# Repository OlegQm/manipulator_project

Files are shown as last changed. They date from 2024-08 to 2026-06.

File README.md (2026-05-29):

# Autonomous Object Recognition Manipulator

This is a solo project by **Oleh Savchenko** focused on building a self-made autonomous manipulator that can detect objects and react to user commands from a mobile app. The repository now combines hardware control, on-device vision, mobile UX, and a separate multimodal chatbot service for image Q&A.

---

## 📷 Photos

bird_photo_for_readme_1
bird_photo_for_readme_2

---

## Project Structure

```
├── 3D_models
│   └── [3D models for printing device components]
├── programs
│   ├── arduino
│   │   ├── servos_and_led             # Servo + LED control sketch
│   │   └── old/esp32                  # Legacy ESP32 camera code
│   ├── mobile
│   │   └── manipulatorMobileApp       # Mobile app source code
│   ├── multimodal_chatbot             # FastAPI + LangGraph image Q&A service
│   └── objects_detection
│       ├── pt_to_hef_converter        # Convert trained models to HEF format
│       ├── robotic_arm_scripts        # Raspberry Pi + Hailo runtime scripts
│       └── custom_model               # Custom YOLO model configs and training assets
└── README.md
```

### 3D\_models

Contains all 3D-printable models for assembling the manipulator device.

### programs

* **arduino**: Arduino sketches for low-level manipulator control (servos/LED) and archived ESP32 experiments.
* **mobile/manipulatorMobileApp**: Xamarin.Forms mobile client (Android/iOS) used to configure bot access, send commands, and work with detected object lists.
* **objects\_detection**: Raspberry Pi object detection stack, custom model assets, and scripts for manipulator interaction.
* **multimodal\_chatbot**: Dockerized FastAPI service (LangGraph-based) that accepts text + image and returns responses, with Redis sessions and Nginx basic auth.

---

## 🌐 System Workflow

1. **User Request**: The user sends a command from the mobile app (for example, request screenshot / object list / selection).
2. **Bot Transport Layer**: Communication is currently handled through Telegram bot endpoints to keep infrastructure simple and low-cost.
3. **Detection Runtime**: The Raspberry Pi module in `programs/objects_detection/robotic_arm_scripts` runs inference (with Hailo acceleration when enabled).
4. **Result Delivery**: The app receives an image and/or recognized object names and renders them for user interaction.
5. **Selection Command**: The user chooses an object or action, and the command is sent back through the same channel.
6. **Actuation**: The detection/control side sends control signals to Arduino logic that drives the manipulator servos.

In parallel, the repository also includes `programs/multimodal_chatbot`, a standalone API flow for image + text question answering.



---

## 🍓 Raspberry Pi

The Raspberry Pi is the main compute node for on-device vision and control scripts. In the current setup, it works as the bridge between camera inference and actuator logic, and interfaces with:

* **Battery pack**
* **Arduino**
* **Display**
* **Power button**

raspberry_pi_newest_device

---

## 🤖 Hailo AI Kit

The project uses the Hailo AI Kit as a hardware accelerator for real-time detection. The measured project-level comparison remains:

* **Raspberry Pi CPU**: YOLOv8n at 256×256 resolution → \~9 FPS
* **Hailo AI Kit**: YOLOv8m at 640×640 resolution → >100 FPS

ai_kit_newest_device

---

## 🖨️ 3D Models

The mechanical design combines EEZYbotARM-based parts (purple) with custom printed components (black) adapted for this build.



---

## 📱 Mobile Application

The mobile client is implemented with Xamarin.Forms and currently communicates with the device via Telegram bots. Typical setup:

1. Create two bots in a single chat:

   * **Manipulator bot** (device-side command receiver)
   * **User bot** (app-side interaction bot)
2. In the app, provide bot token and chat ID in the server settings screen.
3. Choose one of two operation modes:

   * **Objects List**: Manage/filter object names and send direct selection commands.
   * **Possible Objects**: Request fresh screenshot + caption from the device and pick from currently detected items.
4. Send a request, review response, and dispatch selection/search commands.

The app also supports object filtering by text prompt and by photo, which helps when the exact object name is unknown.




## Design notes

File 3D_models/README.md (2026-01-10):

# 3D Parts for the Device

- 1x - print once
- 2x - print twice
- 3x - print three times
- 4x - print four times

The `1x` folder also contains an `old` folder that stores the 3D models needed for earlier versions of the robotic arm.

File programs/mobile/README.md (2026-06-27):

# manipulatorMobileApp

`manipulatorMobileApp` is a Xamarin.Forms mobile application used to control the
robotic arm prototype, request camera screenshots through Telegram, select tracked
objects, and optionally discuss the latest image with a multimodal chatbot backend.

---

## Features

- Stores Telegram server/bot settings locally with SQLite.
- Sends control commands to the robotic arm through Telegram Bot API.
- Requests the current camera image and displays the returned object list.
- Sends `/selection`, `/searching`, and `/flashlight` commands.
- Maintains a local object database and supports manual, text-prompt, and photo-based filtering.
- Opens a chat page that sends the displayed image to the chatbot backend and keeps a server-side session for follow-up questions.

---

## Prerequisites

- **Visual Studio Community 2022**
  - Ensure you have the **Xamarin.Forms** workload installed
- **Android SDK** (installed via Visual Studio installer)
- **Xcode** (for iOS builds on macOS)
- .NET tooling that ships with Visual Studio for Xamarin development
- Telegram bot token and chat/channel ID for communication with the robotic arm
- Optional chatbot server URL and Basic Auth credentials
- `api_key.txt` in the application data path when OpenAI-based object-list filtering is used

---

## Solution structure

`manipulatorMobileApp.sln`

- `manipulatorMobileApp/` — shared Xamarin.Forms project
  - `App.xaml`, `App.xaml.cs` — app bootstrap and navigation root
  - `MainPage.xaml(.cs)` — entry page
  - `Views/`
    - `ModeSelectionPage` — chooses operating mode
    - `NotesPage`, `NoteAddingPage` — notes list and creation flow
    - `ScreenshotPage` — camera screenshot, available objects, and chatbot entry
    - `ChatPage` — image-based chatbot conversation
  - `Services/`
    - `TelegramService.cs` — Telegram Bot API communication
    - `ChatbotService.cs` — REST client for the multimodal chatbot backend
  - `Helpers/`
    - `SearchingToggleHelper.cs`, `FlashlightToggleHelper.cs` — shared Telegram command toggles
    - `SafeAreaHelper.cs` — platform-safe layout helper
  - `Controls/`
    - `ChatInputEditor.cs` — custom chat input editor
  - `Data/`
    - `RecordsDB.cs` — SQLite helper for `Record` entities
    - `ServersDB.cs` — SQLite helper for `Server` entities
  - `Models/`
    - `Record.cs`, `Server.cs`, `ChatMessage.cs` — model definitions
  - `IToast.cs`, `IFileHelper.cs` — dependency-service contracts implemented per platform
- `manipulatorMobileApp.Android/`
  - `MainActivity.cs` — Android entry point
  - `FileHelperDroid.cs`, `ToastDroid.cs` — Android-specific DI implementations
  - `Renderers/ChatInputEditorRenderer.cs` — Android renderer for the chat input
  - `Resources/` — icons, styles, manifests, assets
- `manipulatorMobileApp.iOS/`
  - `AppDelegate.cs`, `Main.cs` — iOS entry points
  - `FileHelperiOS.cs`, `ToastIOS.cs` — iOS-specific DI implementations
  - `Assets.xcassets/`, `Resources/`, `Info.plist`, entitlements

---

## App flow and logic

- **Startup** (`App.xaml.cs`)
  - Initializes dark theme and navigation root (`NavigationPage -> MainPage`).
  - Lazy-creates SQLite databases for notes (`RecordsDB`) and servers (`ServersDB`) in `LocalApplicationData`.
  - Loads a list of standard object names from `names.names` via `IFileHelper`; exposes it as `GlobalWordsArray`.
  - On failure to load words, shows a toast via platform `IToast`.

- **Main screen (servers)** (`MainPage`)
  - Editors for server name, bot token, chat ID, optional chatbot URL, and optional Basic Auth credentials; saves to `ServersDB`.
  - Lists saved servers with swipe-to-delete and “Delete All”.
  - On selection, populates editors from the chosen server.
  - “Start”/toolbar “Start” opens **ModeSelectionPage** with the current Telegram settings and optional chatbot settings. Server name, bot token, and chat ID are required.

- **Mode selection** (`ModeSelectionPage`)
  - Two branches: **NotesPage** (“OBJECTS LIST”) and **ScreenshotPage** (“POSSIBLE OBJECTS”).
  - `NotesPage` receives the Telegram token/chat ID.
  - `ScreenshotPage` also receives the chatbot URL and authentication values.

- **Notes list & actions** (`NotesPage`)
  - Loads/saves `Record` entries from `RecordsDB`; search bar filters locally by title.
  - “Add” opens `NoteAddingPage` for create/edit; swipe-to-delete removes a record; “Delete All” drops and recreates the table.
  - **Edit mode** toggle: tap navigates to `NoteAddingPage` for the selected record; otherwise tap sends `/selection <Title>` to the Telegram bot (HTTP POST).
  - **Default Buttons**: reloads `GlobalWordsArray` into the DB after confirmation, replacing existing entries.
  - **Filter by prompt**: sends a text prompt with the known object list to OpenAI (`gpt-4o-mini`), splits the response into keywords, filters records by those keywords.
  - **Filter by photo**: captures a photo (permissions via `Xamarin.Essentials`), resizes with SkiaSharp, calls OpenAI vision (`gpt-4o-mini`) with the image and known object list, then filters records by returned keywords.
  - **OFF/ON searching**: toggles `/searching 0/1` via Telegram; **Turn on/off flashlight** sends `/flashlight ON/OFF`.

- **Add/Edit note** (`NoteAddingPage`)
  - Binds a `Record`; loads by ID when navigated from edit mode.
  - Saves or updates on “Save”; deletes on “Delete”; auto-updates DB on text/title change to keep timestamps in sync.
  - Toolbar utilities: clear text, replace double spaces, scroll to top/bottom, change text/background colors.
  - Auto-generates a title from the first 45 chars of the description if the title is empty.

- **Screenshot & available objects** (`ScreenshotPage`)
  - Initially displays a built-in placeholder image and enables the Chat toolbar item, so the chatbot can be tested even before a real screenshot is received.
  - “SCREENSHOT” sends `/get_image` to the Telegram bot, then polls `getUpdates` to fetch the latest photo and caption; displays the image and splits the caption into available object items.
  - Selecting an item sends `/selection <word>` to the bot.
  - Toolbar toggles send `/searching 0/1` and `/flashlight ON/OFF`.
  - The Chat toolbar item opens `ChatPage` with the currently displayed image. If no Telegram screenshot has been fetched yet, the placeholder image is used.

- **Chatbot conversation** (`ChatPage`)
  - Creates a server-side chatbot session with `POST /api/v1/sessions` when the page opens.
  - Sends the currently displayed image as Base64 only with the first chat message.
  - Sends later messages as text-only; the backend keeps the image in the same session and can reuse it for follow-up questions.
  - Deletes the session with `DELETE /api/v1/sessions/{session_id}` when the chat page disappears. Errors during deletion are intentionally ignored because server cleanup also handles expired sessions.

---

## Data and services

- **SQLite**: `RecordsDB` and `ServersDB` wrap SQLiteAsyncConnection; create tables on first use; provide CRUD plus helpers (last server, filter records by keywords, drop/reset).
  `Server` records also store optional chatbot URL, username, and password.
- **DependencyService contracts**:
  - `IFileHelper` — resolve platform file paths (used to load `names.names`, `api_key.txt`).
  - `IToast` — platform toast notifications.
- **External APIs**:
  - Telegram Bot API (`sendMessage`, `getUpdates`, `getFile`) for bot control, screenshot retrieval, and selection commands.
  - OpenAI Chat/Vision (`gpt-4o-mini`) for object-list filtering in `NotesPage`.
  - Multimodal chatbot REST API (`/api/v1/sessions`, `/api/v1/chat`, `/api/v1/sessions/{id}`) for image-based conversation in `ChatPage`.
  - Network access checked via `Xamarin.Essentials.Connectivity`; camera via `MediaPicker` with runtime permissions.

---

## Build and run

1. **Open in Visual Studio 2022**
   - Launch Visual Studio Community 2022
   - Select **File → Open → Project/Solution**
   - Navigate to `manipulatorMobileApp/manipulatorMobileApp.sln` and open it

2. **Restore NuGet packages**
   - In **Solution Explorer**, right-click the solution and choose **Restore NuGet Packages**

3. **Configure runtime values**
   - Add a Telegram bot token and chat ID on the main screen.
   - Add chatbot URL and Basic Auth values only if `ChatPage` should call the multimodal chatbot backend.
   - Add `api_key.txt` only if prompt/photo filtering in `NotesPage` should use OpenAI.

4. **Deploy to device or emulator**
   - Set the **Startup Project** to your desired platform (Android or iOS)
   - Choose an emulator or connected device
   - Press **F5** to build and run

---

## Usage notes

- Use **OBJECTS LIST** when selecting from the local object database.
- Use **POSSIBLE OBJECTS** when requesting a live camera screenshot and selecting one of the detected objects.
- Open **Chat** from the screenshot screen to ask questions about the currently displayed image.
- The first chatbot message includes the image; follow-up messages rely on the same server-side session.

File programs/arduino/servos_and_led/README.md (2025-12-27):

# Background

The device is controlled by three servos via Arduino:
The left and right servos are used to adjust the camera height.
The bottom servo (in the base) rotates the device.

I could have done without Arduino, but I added it as an extra layer against high-voltage events and incorrect wiring.

# Arduino Servo Controller

This sketch reads rotation angles and drives three servo motors on an Arduino Uno.

## Wiring

- **Flashlight** → Data Pin 5
- **Base servo** → Data Pin 4
- **Left servo** (camera facing you) → Data Pin 3
- **Right servo** → Data Pin 2 
- **All servos and flashlight** → +5 V (use common ground with Arduino)

## Installation

1. Open the `.ino` file in the Arduino IDE. 
2. Select **Arduino Uno** as the board. 
3. Upload at 115200 bps.

## Usage

1. Send angle data over Serial (e.g. `$090090060` (`$090` - 90 deg, `$090` - 90 deg, `$060` - 60 deg)).
2. The sketch parses each value and moves the corresponding servo.
3. Send `@ON` to turn the flashlight on and `@OFF` to turn it off.

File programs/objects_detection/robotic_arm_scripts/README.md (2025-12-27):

# Robotic arm with objects following system

This folder contains the detection module that runs on a Raspberry Pi with a Hailo accelerator. It uses a custom model, based on YOLOv8m model to detect objects for the manipulator project.

## Setup

Run the installation script to create the virtual environment and download necessary resources:

```bash
cd hailo_scripts
./install.sh
cd ..
```

## Running

Start the detection pipeline with the provided model:

```bash
python3 hailo_remote_detection.py -i rpi -u \
    --hef models/dataset_v5_models/hailo_models/own_yolov8m_lca_light_v2_quantized_model.hef \
    --labels-json hailo_scripts/labels.json
```

Adjust the model or labels if you use your own dataset.

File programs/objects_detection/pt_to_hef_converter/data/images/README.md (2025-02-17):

Images from your dataset (in my case 3664 validation images)

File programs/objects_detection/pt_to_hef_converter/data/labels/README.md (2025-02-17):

Labels from your dataset (in my case 3664 validation labels), corresponding to images

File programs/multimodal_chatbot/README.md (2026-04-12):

# Multimodal Chatbot

A multimodal chatbot REST API that accepts images and text to answer questions. Built with **FastAPI**, **LangGraph**, and **OpenAI GPT-5-mini**.

## Features

- **Multimodal**: Send images (base64) + text questions, get intelligent answers
- **Session-based**: Per-session chat history stored in Redis
- **Token management**: Tracks token usage with tiktoken, enforces context window limits
- **Auto-cleanup**: Expired sessions (>1h inactivity) automatically purged every 10 minutes
- **Dockerized**: Single `docker compose up` starts all services
- **Secured**: Nginx reverse proxy with HTTP Basic Authentication
- **CI/CD**: GitHub Actions pipeline with automated tests and SSH deployment

## Quick Start

### Prerequisites

- Docker and Docker Compose
- OpenAI API key

### 1. Configure environment

```bash
cd programs/multimodal_chatbot
cp .env.example .env
# Edit .env with your actual values (API key, auth credentials)
```

### 2. Start the application

```bash
docker compose up -d --build
```

This starts 3 services:
- **app** — FastAPI application on internal port 8000
- **redis** — Redis 7 for session storage
- **nginx** — Reverse proxy on port 80 with basic auth

### 3. Verify

```bash
curl http://localhost/health
# {"status": "ok", "redis": "connected"}
```

## API Usage

All endpoints (except `/health`) require HTTP Basic Auth.

### Create a session

```bash
curl -u admin:password -X POST http://localhost/api/v1/sessions
# {"session_id": "abc-123...", "created_at": "..."}
```

### Send a text message

The client sends only the current message. The service loads the existing
conversation history from Redis by `session_id`.

```bash
curl -u admin:password -X POST http://localhost/api/v1/chat \
  -H "Content-Type: application/json" \
  -d '{"session_id": "abc-123...", "message": "Hello!"}'
```

### Send an image + question

```bash
IMAGE_B64=$(base64 -w0 photo.jpg)
curl -u admin:password -X POST http://localhost/api/v1/chat \
  -H "Content-Type: application/json" \
  -d "{\"session_id\": \"abc-123...\", \"message\": \"What is this?\", \"image\": \"$IMAGE_B64\"}"
```

### Get chat history

This endpoint is optional for clients that need to display or debug the stored
conversation. It is not required when sending messages to `/api/v1/chat`.

```bash
curl -u admin:password http://localhost/api/v1/sessions/abc-123.../history
```

### Delete a session

```bash
curl -u admin:password -X DELETE http://localhost/api/v1/sessions/abc-123...
```

## Environment Variables

| Variable | Default | Description |
|---|---|---|
| `OPENAI_API_KEY` | — | **Required.** OpenAI API key |
| `OPENAI_MODEL` | `gpt-4o-mini` | OpenAI model name |
| `REDIS_URL` | `redis://redis:6379/0` | Redis connection string |
| `SESSION_TTL_SECONDS` | `3600` | Session inactivity timeout (seconds) |
| `CLEANUP_INTERVAL_SECONDS` | `600` | Cleanup job interval (seconds) |
| `MAX_CONTEXT_TOKENS` | `100000` | Max tokens per session |
| `BASIC_AUTH_USER` | `admin` | Nginx basic auth username |
| `BASIC_AUTH_PASSWORD` | `changeme` | Nginx basic auth password |
| `LOG_LEVEL` | `INFO` | Python logging level |

## Project Structure

```
programs/multimodal_chatbot/
├── docker-compose.yaml       # Docker services definition
├── pytest.ini                # pytest configuration
├── .env / .env.example       # Environment configuration
├── app/
│   ├── Dockerfile            # App container image
│   ├── requirements.txt      # Runtime Python dependencies
│   ├── main.py               # FastAPI entry point
│   ├── config.py             # Pydantic BaseSettings
│   ├── models/               # Request/response schemas
│   ├── routers/              # API endpoints
│   ├── services/             # Business logic (agent, sessions, cleanup)
│   └── tools/                # LangGraph tools
├── nginx/                    # Nginx config + Dockerfile
├── tests/                    # pytest test suite
│   ├── Dockerfile            # Test runner container image
│   └── requirements.txt      # Test dependencies (references app/requirements.txt)
└── agent-instructions/       # Documentation
```

## Testing

Tests run inside a dedicated Docker container via the `test` profile:

```bash
# Run all tests in Docker (recommended)
cd programs/multimodal_chatbot
docker compose --profile test run --rm tests
```

Each container has its own `requirements.txt`:
- `app/requirements.txt` — runtime dependencies
- `tests/requirements.txt` — test dependencies (references app deps via `-r`)

## Deployment

Push to `main` branch triggers automatic deployment via GitHub Actions:
1. Tests run in CI
2. On success, code is synced to EC2 via SSH
3. Docker Compose rebuilds and restarts services

See [agent-instructions/deployment/server-setup.md](agent-instructions/deployment/server-setup.md) for manual setup.

## Documentation

- [Implementation Plan](agent-instructions/PLAN.md)
- [Architecture Overview](agent-instructions/architecture/overview.md)
- [API Reference](agent-instructions/api/endpoints.md)
- [Deployment Guide](agent-instructions/deployment/server-setup.md)

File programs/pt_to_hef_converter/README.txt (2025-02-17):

1) Create environment (YOLO) with Python 3.8.20 (`venv_yolov8` in my case):

After that activate environment:
`source venv_yolov8/bin/activate`

Then donload the 3.27.0 Hailo dataflow compiler (https://hailo.ai/?dl_dev=1&file=8791984ee2b2999850f5a55fbdb8c46f)
from https://hailo.ai/developer-zone/software-downloads/. You may need to register here.
Copy the downloaded file to the same directory as `hailo_model_zoo-2.11.0-py3-none-any.whl`.

And install modules:
`pip install -r yolo_env_requirements.txt`

Then copy your .pt model in `/pt_to_hef_converter`,
for instance `yolov8m_model_v15_640.pt` (my case), and execute in terminal:
`yolo export model=./yolov8m_model_v15_640.pt imgsz=640 format=onnx opset=11`

2) Create environment (HAILO) with Python 3.8.20 (`venv_hailo` in my case):

After that activate environment:
`source venv_hailo/bin/activate`

And install modules:
`pip install -r hailo_env_requirements.txt`

Then enter your model name instead of `yolov8m_model_v15_640`, `yolov8m_model_v15_640.onnx`
and `yolov8m_model_v15_640.har` in `steps/parse.py`. `yolov8m_640_v15` is the folder where the
`yolov8m_model_v15_640.onnx` and `yolov8m_model_v15_640.har` will be saved:

`onnx_model_name = 'yolov8m_model_v15_640'`
`onnx_path = 'yolov8m_640_v15/yolov8m_model_v15_640.onnx'`
`har_path = 'yolov8m_640_v15/yolov8m_model_v15_640.har'`

Then move to https://netron.app/ (or any other model) and visualize your `.onnx` (in the future instructions I will refer
to yolov8m_640_v15/yolov8m_model_v15_640.onnx` visualization, that's my case):
On the image you will find the last `Concat` layer, which includes the 3 arrows (`/model.22/Concat_3` on
`yolov8m_model_v15_640.onnx` visualization).

Then go up the leftmost branch of this word all the way to `Reshape'. After that you will see 2 `Conv` layers.
Click on the left one (`/model.22/cv2.0/cv2.0.2/Conv` in my case) and copy its name (`name`),
do the same with the second one (`/model.22/cv3.0/cv3.0.2/Conv` in my case)
and copy its name right after the first one.
Do the same with the rest of the layers, saving all the names one after the other. I have such a list:
`[
        '/model.22/cv2.0/cv2.0.2/Conv',
        '/model.22/cv3.0/cv3.0.2/Conv',
        '/model.22/cv2.1/cv2.1.2/Conv',
        '/model.22/cv3.1/cv3.1.2/Conv',
        '/model.22/cv2.2/cv2.2.2/Conv',
        '/model.22/cv3.2/cv3.2.2/Conv'
]`
After that, copy this list instead of mine into `steps/parse.py`.

Then go to the terminal and execute:
`python3.8 steps/parse.py`

3) Add images to `data/images` following the instructions in `data/images/README.txt`, and add captions to `data/labels`.
Also add the images to `calibration_set` as instructed in `calibration_set/README.txt`.
Then open `steps/optimize.py` and in `MODEL_NAME`, copy the same name that was in the `steps/parse.py` file in `har_path`.
Now enter the number of classes from the dataset in `NUM_CLASSES` and enter the image size in the `.pt` model to `IMG_SIZE`.

Then visualise the `.har` model using the `hailo visualizer yolov8m_640_v15/yolov8m_model_v15_640.har`
command (`yolov8m_640_v15/yolov8l_model_v16_640.svg` in my case).

Now find all 6 output layers: `output_layer1`, `output_layer2`,..., `output_layer6` and look at the `conv` layers in front of each of them.
In my case (`yolov8l_model_v16_640.svg`) these are layers `conv57`, `conv58`, `conv70`, `conv71`, `conv82` and `conv83`, keep these names.
After that copy the file `config/postprocess_config/yolov8m_nms_config.json` to yourself and replace my names with your own,
you can also rename the file as desired. Also specify the path to this file in `alls`:

alls = '''
quantisation_param([conv58, conv71, conv83], force_range_out=[0.0, 1.0])
normalisation1 = normalization([0.0, 0.0, 0.0, 0.0], [255.0, 255.0, 255.0])
nms_postprocess("config/postprocess_config/yolov8m_nms_config.json" meta_arch=yolov8, engine=cpu)
'''
Also in `alls` replace the names `[conv58, conv71, conv83]` with the names of the `conv` layers before `output_layer2`,
`output_layer4` and `output_layer6`.

Then go to the terminal and execute:
`python3.8 steps/optimize.py`

4) Go to `steps/compile.py`. Replace `model_name` with your model name. Then go to the terminal and execute:
`python3.8 steps/compile.py`

After this command you will get your `.hef` file, the command may take a long time.

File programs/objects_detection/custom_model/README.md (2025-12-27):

Custom Ultralytics YOLO Extensions
==================================

This repository packages a customized [Ultralytics 8.3.160](https://community.ultralytics.com/t/new-release-ultralytics-v8-3-160/1185) build with additional layers for better small-object detection. The key addition is Local Context Attention (LCA), wired into Ultralytics' registry so it can be used directly in model YAMLs. A reference model (`own_yolov8m_lca_light_v2.yaml`) shows how to integrate the new blocks.

Contents
--------
- `ultralytics_custom/`: editable Ultralytics package with custom modules registered.
- `ultralytics_custom/ultralytics/nn/modules/custom_modules.py`: LCA, ConvLCA, and a Hailo-friendly Detect head.
- `own_yolov8m_lca_light_v2.yaml`: example YOLOv8 model using the custom layers.
- `trainer.py`: training entrypoint with default hyperparameters and resume/debug switches.
- `setup_yolo_env.sh`: helper to provision a Python 3.12 venv, install GPU drivers, and install the editable package.

Requirements
------------
- Python 3.12 (script installs `python3.12` and `python3.12-venv` on Ubuntu).
- NVIDIA driver/toolkit for GPU training (script installs driver 535).
- Access to the dataset repo `https://github.com/OlegQm/manipulator_project_datasets` (clone happens in the setup script).

Quickstart (scripted)
---------------------
1. Set the path to this project in `setup_yolo_env.sh`:
   - Edit `PATH_TO_CUSTOM_YOLO_MODEL_TRAINER` to the parent directory that contains `ultralytics_custom`.
2. Run the setup:
   ```bash
   bash setup_yolo_env.sh
   ```
   The script will clone the dataset repo (if accessible), fetch a sample image, create the `yolo_trainer` venv, and install the package in editable mode.

Manual Installation
-------------------
```bash
cd ultralytics_custom
python3.12 -m venv ../yolo_trainer
source ../yolo_trainer/bin/activate
pip install --upgrade pip
pip install -e .
```
If you need the demo image, download it to `ultralytics_custom/ultralytics/assets/`:
```bash
wget -nc https://ultralytics.com/images/bus.jpg -P ultralytics_custom/ultralytics/assets/
```

Training
--------
- Configure `trainer.py`:
  - `model_cfg`: path to a model YAML (e.g., `own_yolov8m_lca_light_v2.yaml`).
  - `data_cfg`: path to your `data.yaml`.
  - Toggle `FAST_DEBUG` for a 1-epoch sanity run; toggle `RESUME` to continue from a previous checkpoint in `runs/train/.../weights/best.pt`.
- Launch training:
  ```bash
  source yolo_trainer/bin/activate
  python trainer.py
  ```

Custom Layers
-------------
- `LocalContextAttention`: depthwise conv + bottleneck + sigmoid gate for local context.
- `LCA`: attention-only wrapper; use it like `- [from, 1, LCA, [channels]]`.
- `ConvLCA`: convolution followed by LCA; drop-in where ConvSE might be used.
- `Detect_HailoFriendly`: identical to Ultralytics Detect during training; splits bbox/cls heads separately during ONNX export for Hailo compatibility.

Example model usage (`own_yolov8m_lca_light_v2.yaml`)
-----------------------------------------------------
```yaml
backbone:
  - [-1, 1, ConvLCA, [128, 3, 2]]
  - [-1, 1, LCA,     [128]]

head:
  - [-1, 1, C2f, [128, False, ConvLCA]]   # LCA-enhanced head block
  - [[23, 26, 29], 1, Detect_HailoFriendly, [nc]]
```
Use this file as a template for new architectures; the custom modules are already registered in the package.

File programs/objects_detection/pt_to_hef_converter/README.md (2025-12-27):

# YOLO and HAILO Setup Guide (On Ubuntu 24.04, officially not supported)

## 1) Create environment (YOLO) with Python 3.10.18 (you may need to install it)

Create a virtual environment (`venv_yolov8` in my case):

```sh
python3.10 -m venv venv_yolov8
```

Activate the environment:

```sh
source venv_yolov8/bin/activate
```

Then download the **3.27.0 Hailo dataflow compiler** ([direct link](https://hailo.ai/?dl_dev=1&file=8791984ee2b2999850f5a55fbdb8c46f)) 
from [Hailo Developer Zone](https://hailo.ai/developer-zone/software-downloads/). You may need to register.

Copy the downloaded file to the same directory as `hailo_model_zoo-2.11.0-py3-none-any.whl`.

Now install the required modules:

```sh
pip install -r yolo_env_requirements.txt
```

Then copy your `.pt` model to `<path_to>/pt_to_hef_converter/steps`,
for instance `best.pt` (in my case), and execute in terminal:

```sh
python3 simpify_model.py
```

And the copy best_fused.onnx to local_attenttion_yolov8m folder

---

## 2) Create environment (HAILO) with Python 3.10.18

Create a virtual environment (`venv_hailo` in my case):

```sh
deactivate
python3.10 -m venv venv_hailo
```

Install system dependencies (Ubuntu):

```sh
sudo apt update
sudo apt install -y \
    python3.10-dev python3.10-distutils \
    build-essential cython3 pkg-config \
    graphviz libgraphviz-dev
```

Activate the environment:

```sh
source venv_hailo/bin/activate
```

Now install the required modules:

```sh
python -m pip install -U pip wheel "setuptools<60"
python -m pip install numpy==1.23.5 cython==0.29.36
python -m pip install --no-binary :all: --no-build-isolation lap==0.4.0

python -m pip install --no-deps \
    hailo_dataflow_compiler-3.27.0-py3-none-linux_x86_64.whl \
    hailo_model_zoo-2.11.0-py3-none-any.whl

pip install -r hailo_env_requirements.txt
```

Then enter your model name instead of `own_yolov8m_lca_light_v2`, `own_yolov8m_lca_light_v2.onnx` and `own_yolov8m_lca_light_v2.har` in `steps/parse.py`.
`local_attenttion_yolov8m` is the folder where `own_yolov8m_lca_light_v2.onnx` and `own_yolov8m_lca_light_v2.har` will be saved:

```python
onnx_model_name = 'own_yolov8m_lca_light_v2'
onnx_path = 'local_attenttion_yolov8m/own_yolov8m_lca_light_v2.onnx'
har_path = 'local_attenttion_yolov8m/own_yolov8m_lca_light_v2.har'
```

Then go to [Netron](https://netron.app/) (or any other model visualizer) and
open your `.onnx` model for visualization (`local_attenttion_yolov8m/own_yolov8m_lca_light_v2.onnx` in my case).

When visualizing the model, copy the names of the convolution layers before each output. The output with dimensions `1 * 64 * 20 * 20` is the regression head, and the one with dimensions `1 * 14 * 20 * 20` is the classification head. For example, in my case `/model.30/cv3.2/cv3.2.2/Conv` is the classification part (list all classification parts second), and `/model.30/cv2.2/cv2.2.2/Conv` is the regression part.

You will see two `Conv` layers. Click on the left one (`/model.22/cv2.0/cv2.0.2/Conv` in my case) and copy its name (`name`).
Repeat this for the second one (`/model.22/cv3.0/cv3.0.2/Conv` in my case).
Continue this process for the remaining layers, saving all names sequentially.

I have the following list:

```python
[
    '/model.30/cv2.0/cv2.0.2/Conv', '/model.30/cv3.0/cv3.0.2/Conv',
    '/model.30/cv2.1/cv2.1.2/Conv', '/model.30/cv3.1/cv3.1.2/Conv',
    '/model.30/cv2.2/cv2.2.2/Conv', '/model.30/cv3.2/cv3.2.2/Conv',
]
```

Copy this list and replace it in `steps/parse.py`.

Now execute the following command in the terminal:

```sh
python3.10 steps/parse.py
```

---

## 3) Add Images and Optimize

Add images to `data/images` following the instructions in `data/images/README.txt`,
and add captions to `data/labels`.

Also, add the images to `calibration_set` as instructed in `calibration_set/README.txt`.

Then open `steps/optimize.py`, find `MODEL_NAME`,
and copy the same name from `steps/parse.py` under `har_path`.

Now, enter the number of dataset classes in `NUM_CLASSES`
and specify the image size from the `.pt` model in `IMG_SIZE`.

To visualize the `.har` model, use:

```sh
hailo visualizer local_attenttion_yolov8m/own_yolov8m_lca_light_v2.har
```

(`local_attenttion_yolov8m/own_yolov8m_lca_light_v2.svg` in my case).

Now, locate all 6 output layers: `output_layer1`, `output_layer2`, ..., `output_layer6`.
Identify the `conv` layers preceding each of them.

In my case (`own_yolov8m_lca_light_v2.svg`), they are:

`conv57`, `conv58`, `conv68`, `conv69`, `conv78`, and `conv79`.

Save these names.

Now, copy the file `config/postprocess_config/own_yolov8m_lca_light_v2_nms_config.json`
and replace my names with yours. You can also rename the file as needed
(files for YOLO nano, medium, and large are already included).

Specify the path to this file in `alls`:

```python
alls = '''
quantisation_param([conv58, conv69, conv79], force_range_out=[0.0, 1.0])
normalisation1 = normalization([0.0, 0.0, 0.0, 0.0], [255.0, 255.0, 255.0])
nms_postprocess("config/postprocess_config/own_yolov8m_lca_light_v2_nms_config.json" meta_arch=yolov8, engine=cpu)
'''
```

Also, replace `[conv58, conv69, conv79]`
with the names of the `conv` layers before `output_layer2`, `output_layer4`, and `output_layer6`.

Now execute the following command:

```sh
python3.10 steps/optimize.py
```

After optimization, you can test the resulting model with:

```python
python3 test_har_emulator.py
```

---

## 4) Compile the Model

Open `steps/compile.py` and replace `model_name` with your model name.

Then execute:

```sh
python3.10 steps/compile.py
```

After this command, your `.hef` file will be generated.
The process may take some time.

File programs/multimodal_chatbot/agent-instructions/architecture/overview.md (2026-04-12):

# Architecture Overview

## Tech Stack

| Layer | Technology | Purpose |
|---|---|---|
| API Framework | FastAPI | Async REST API with automatic OpenAPI docs |
| Agent Framework | LangGraph | Stateful agent with tool-calling support |
| LLM | OpenAI GPT-5-mini | Multimodal model (vision + text) |
| Session Storage | Redis | Fast in-memory session/chat history storage |
| Token Counting | tiktoken | Count tokens to enforce context window limits |
| Reverse Proxy | Nginx | Basic auth, request proxying, upload limits |
| Containers | Docker Compose | 4-service stack (app, redis, nginx, tests); Dockerfiles in `app/`, `nginx/`, `tests/` |
| CI/CD | GitHub Actions | Automated testing + SSH deployment |
| Configuration | Pydantic Settings | Type-safe env var management via BaseSettings |

## Data Flow

```
Mobile App
    │
    ▼
┌──────────┐   Basic Auth    ┌──────────────┐   HTTP Proxy   ┌──────────────┐
│  Nginx   │ ──────────────► │  FastAPI App  │ ◄────────────► │    Redis     │
│ (port 80)│                 │ (port 8000)   │                │ (port 6379)  │
└──────────┘                 └──────────────┘                └──────────────┘
                                    │
                                    ▼
                             ┌──────────────┐
                             │  LangGraph   │
                             │    Agent     │
                             │  (GPT-5-mini)│
                             └──────────────┘
```

## Request Flow (POST /api/v1/chat)

1. **Client** sends `session_id`, current `message`, optional `image` (base64) or `image_url`
2. **Nginx** validates basic auth → proxies to FastAPI
3. **FastAPI** validates session exists in Redis
4. **FastAPI** checks token count (tiktoken) — returns 409 if limit exceeded
5. **FastAPI** stores image in Redis (if present) → receives `image_id`
6. **FastAPI** stores user message in Redis
7. **FastAPI** loads prior session history from Redis, builds LangChain message list, and annotates the active image with `[image_id:...]` and `[session_id:...]` markers (image is NOT embedded in context)
8. **LangGraph agent** receives messages, calls `analyze_image` tool with `session_id` + `image_id`
9. **Tool** fetches base64 image from Redis, sends it to the vision model, returns description
10. **Agent** formulates final response incorporating the tool result
11. **FastAPI** stores assistant response in Redis
12. **FastAPI** returns `ChatResponse` with token stats to client

## Image Handling

Images are **not** embedded in the LLM context directly. Instead:
- The image (base64) is stored in Redis under `session:{uuid}:image:{image_id}`
- The agent message contains only a text reference: `[image_id:...] [session_id:...]`
- The agent decides when to call the `analyze_image` tool, which fetches the image from Redis and passes it to the vision model in an isolated call
- This avoids double-spending tokens and keeps the conversation context lightweight
- Images are automatically deleted when the session is deleted or cleaned up

## Session Lifecycle

```
CREATE SESSION ──► CHAT (repeat) ──► DELETE SESSION
      │                                    │
      │         OR                         │
      │                                    │
      └── AUTO-CLEANUP (cron every 10min) ─┘
          deletes sessions inactive > 1 hour
```

## Redis Key Schema

| Key Pattern | Type | Contents |
|---|---|---|
| `session:{uuid}:meta` | Hash | `created_at`, `last_activity` timestamps |
| `session:{uuid}:messages` | List | JSON-serialized message records |
| `session:{uuid}:image:{image_uuid}` | String | Base64-encoded image data |

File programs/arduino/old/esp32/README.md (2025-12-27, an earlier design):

# Background

Previously the device used an ESP32 CAM, which is a standalone module that sends images over HTTP to localhost (wireless). This camera is programmed via Arduino, so I wrote a small script for it — `manipulator_project/programs/arduino/old/esp32/esp32.ino`.

# ESP32-CAM Video Streamer

This sketch boots an ESP32-Wrover module with camera, connects to Wi-Fi, and streams JPEG frames over HTTP.

## Wiring

- **5 V** -> VIN (or 5 V) pin on ESP32 module  
- **GND** -> GND pin on ESP32 module  
- **LED (flash)** -> GPIO 4 (configured as PWM output)  
- **Camera** → Built-in camera header (uses Ai-Thinker pin mapping)  
- **Common ground** between camera module and ESP32

> **Note:** No other external connections are required - power on the board and camera initialization happens in code.

## Configuration

1. Open the `.ino` file in the Arduino IDE (select "ESP32 Wrover Module" as the board).  
2. Set your network credentials:
    
        const char* WIFI_SSID = "WIFI_NETWORK_NAME";
        const char* WIFI_PASS = "WIFI_NETWORK_PASSWORD";
    
3. Optionally adjust:
   - PWM LED brightness (`freq`, `resolution`, `ledOn`, `ledOff`)  
   - JPEG quality (`cfg.setJpeg(80)`)  
   - Resolution presets (`loRes`, `midRes`, `hiRes`)

## Installation

1. Install the **ESP32** board support via Boards Manager.  
2. Install the **esp32cam** library.  
3. Select **115200 bps** for Serial Monitor.  
4. Upload the sketch to your ESP32-Wrover module.

## Usage

1. After power-up, the module will:
   - Initialize camera (hi-res by default)  
   - Connect to Wi-Fi (status printed in Serial)  
   - Start HTTP server on port 80  
2. Check Serial Monitor for your module’s IP address, for example:
    
        http://192.168.1.42
          /cam-hi.jpg
    
3. Open a browser or embed the URL:
   - **High-resolution stream:**  
        
        http://<ESP32_IP>/cam-hi.jpg  
     
   - *(You can enable `/cam-lo.jpg` and `/cam-mid.jpg` by uncommenting the handlers in code.)*

## Endpoints

- **/cam-hi.jpg** → capture at 800×600  
- **/cam-mid.jpg** → capture at 350×530  
- **/cam-lo.jpg** → capture at 320×240

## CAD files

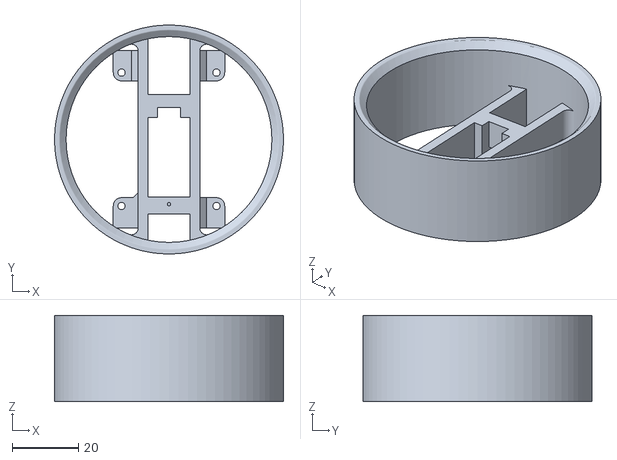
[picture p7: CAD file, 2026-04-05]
3D_models/1x/OWN_01.00.035_robotic_arm_main_box_connector.stl
69.0 x 69.0 x 26.0

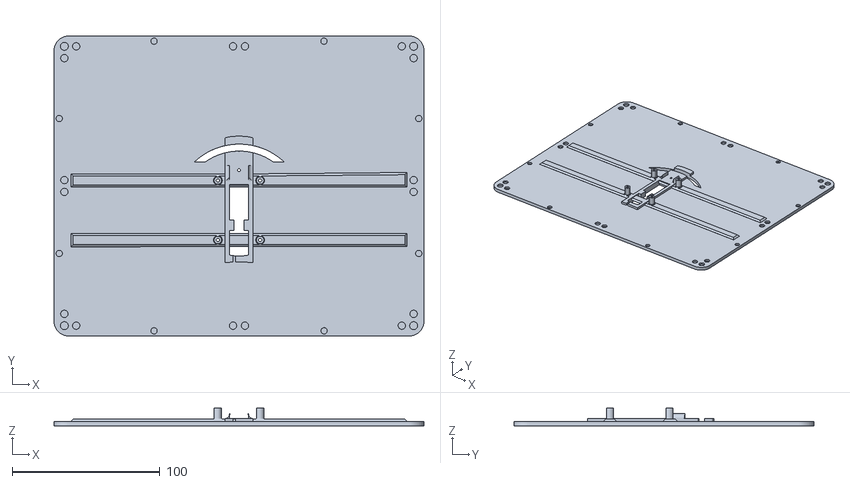
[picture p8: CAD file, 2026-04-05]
3D_models/1x/OWN_01.00.034_main_box_top_plate.stl
250.0 x 202.8 x 12.0

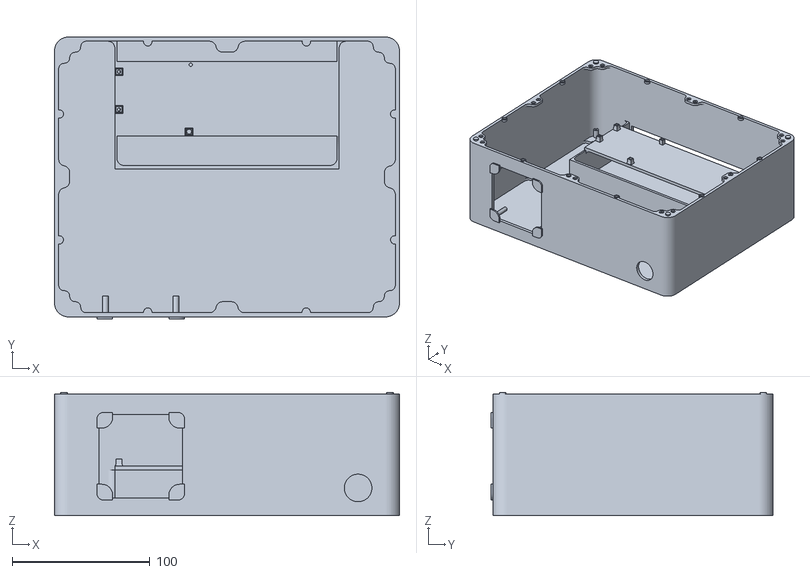
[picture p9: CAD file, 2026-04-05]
3D_models/1x/OWN_01.00.033_main_support_box_part.stl
250.0 x 204.3 x 89.2

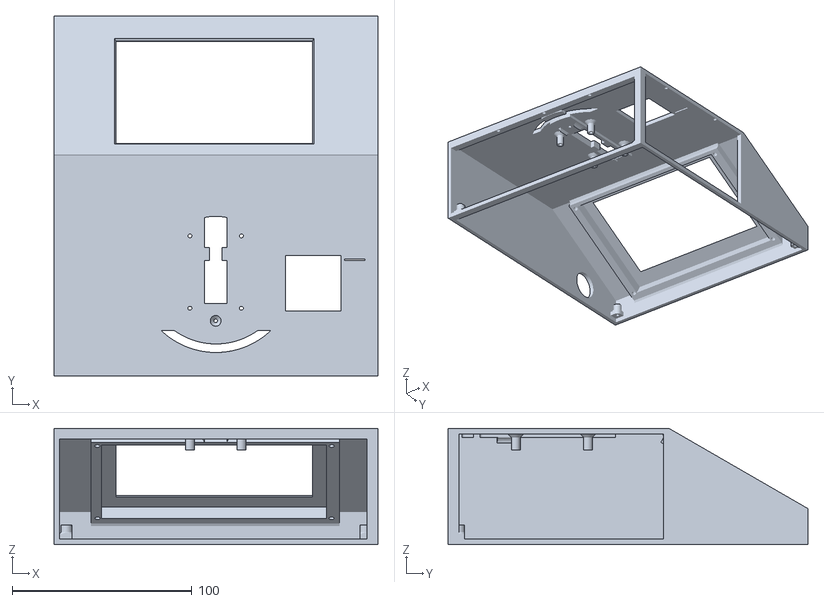
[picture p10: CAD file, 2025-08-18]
3D_models/1x/OWN_01.00.022_box_main_part.stl
180.0 x 200.0 x 64.6

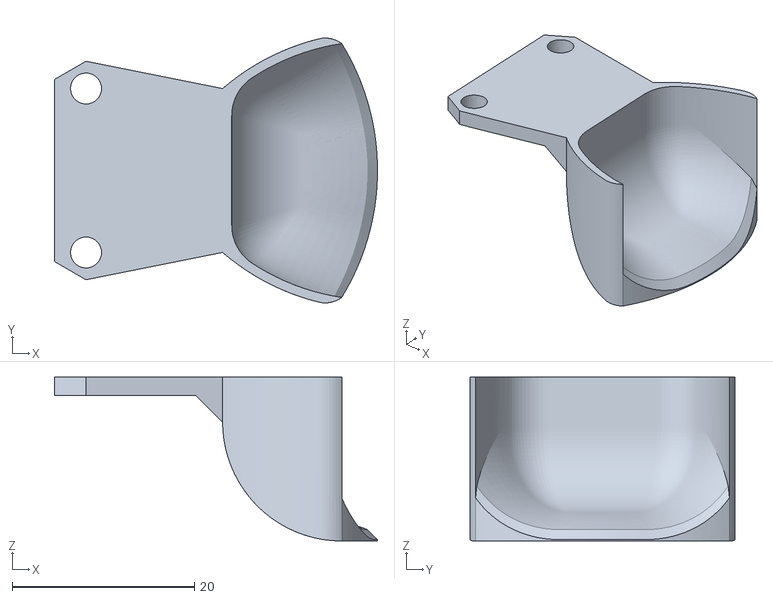
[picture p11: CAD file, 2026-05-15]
3D_models/1x/OWN_01.00.037_led_reflector.stl
35.5 x 29.1 x 18.0

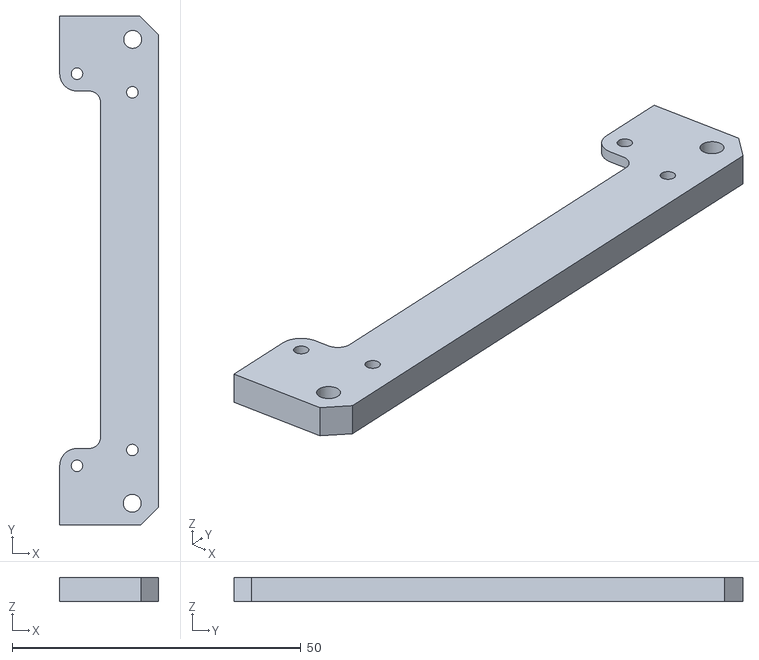
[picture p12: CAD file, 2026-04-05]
3D_models/2x/OWN_01.00.032_display_back_push_holder_part.stl
17.1 x 88.2 x 4.20

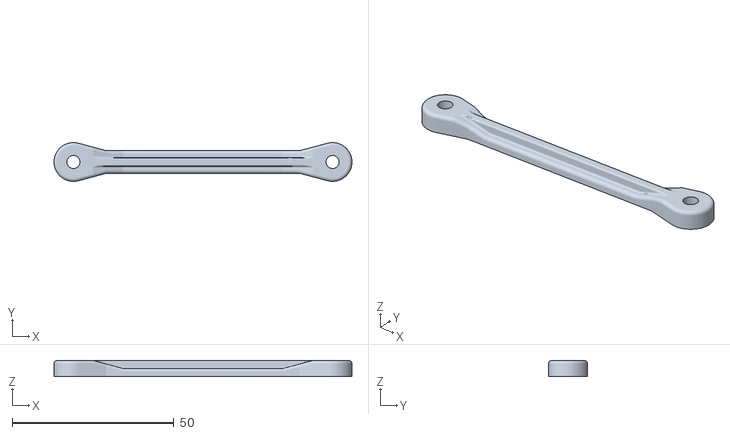
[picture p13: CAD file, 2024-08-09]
3D_models/3x/EBA_01.00.003_link.STL
92.0 x 12.0 x 5.00

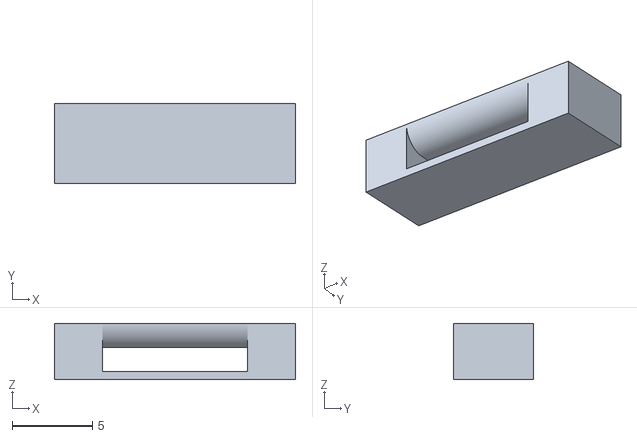
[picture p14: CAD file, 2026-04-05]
3D_models/4x/OWN_01.00.036_plastic_tape_holder.stl
15.0 x 5.00 x 3.50

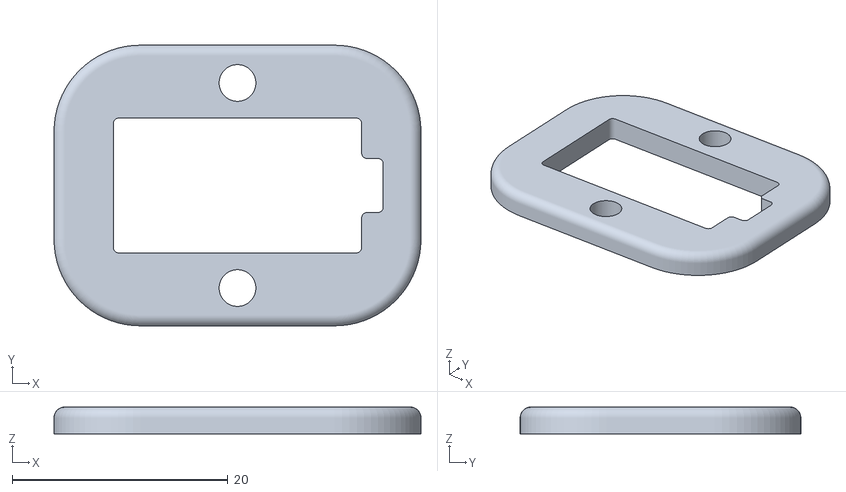
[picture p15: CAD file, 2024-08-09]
3D_models/2x/EBA_01.00.009_servo_plate.STL
34.0 x 26.0 x 2.50

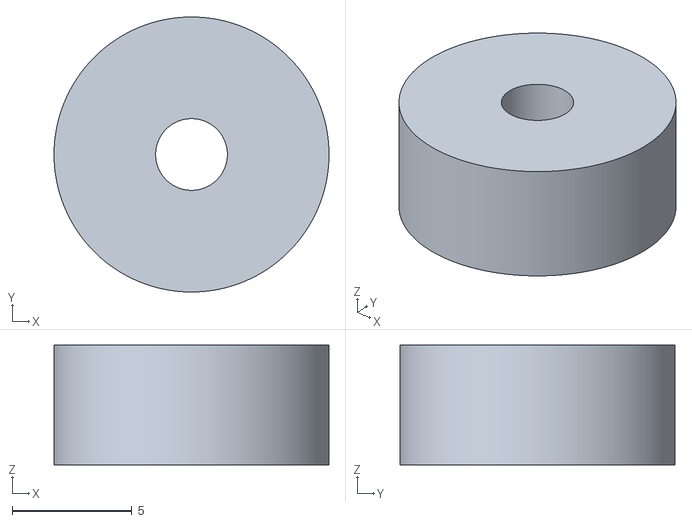
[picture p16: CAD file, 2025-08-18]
3D_models/4x/OWN_01.00.019_bottom_panel_legs.stl
11.5 x 11.5 x 5.00

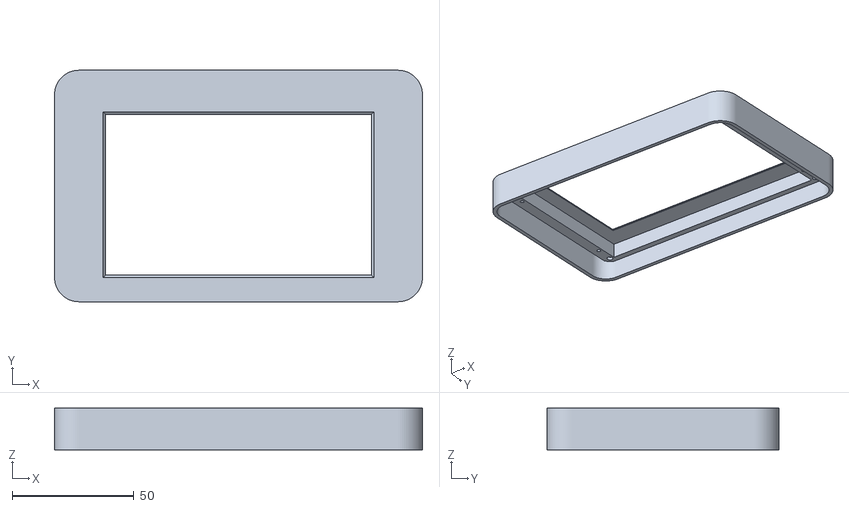
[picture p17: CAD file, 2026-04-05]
3D_models/1x/OWN_01.00.028_display_front_side_holder.stl
151.0 x 95.0 x 17.1

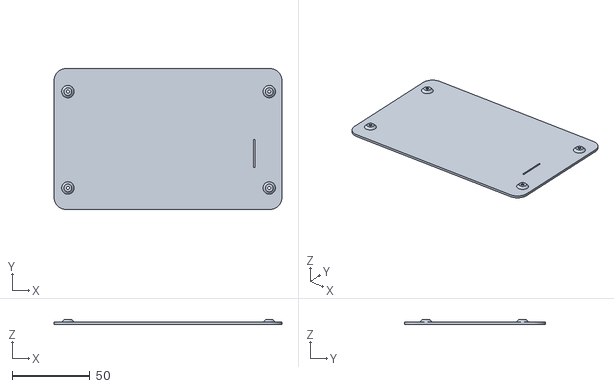
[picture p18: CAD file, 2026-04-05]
3D_models/1x/OWN_01.00.027_display_back_side_holder.stl
146.7 x 90.7 x 3.00

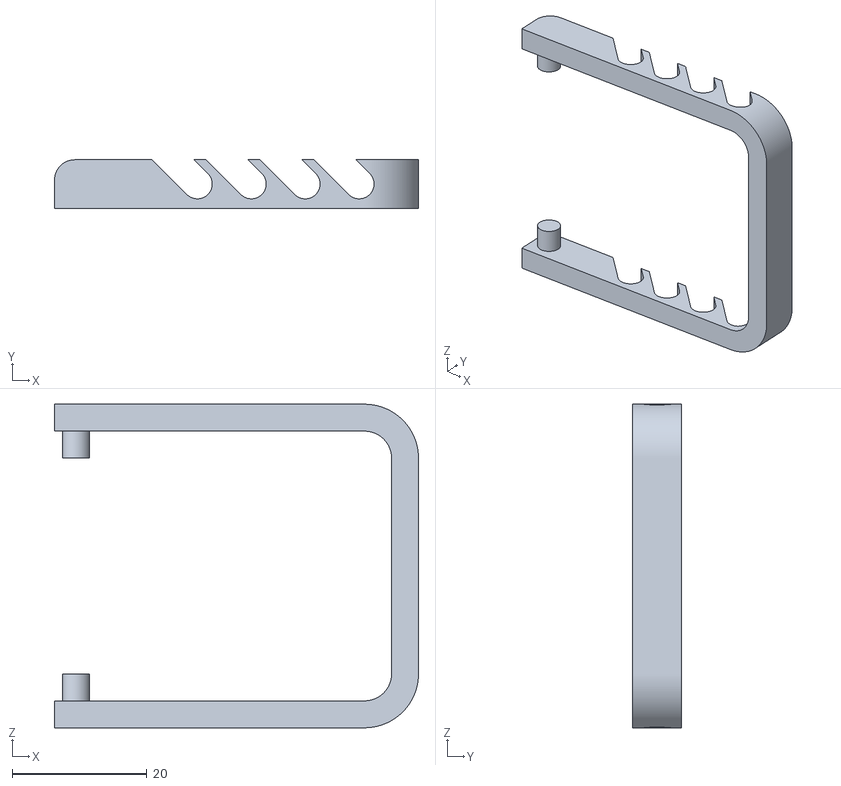
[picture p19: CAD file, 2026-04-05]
3D_models/1x/OWN_01.00.030_display_stand_bottom_part.stl
54.0 x 7.20 x 48.0

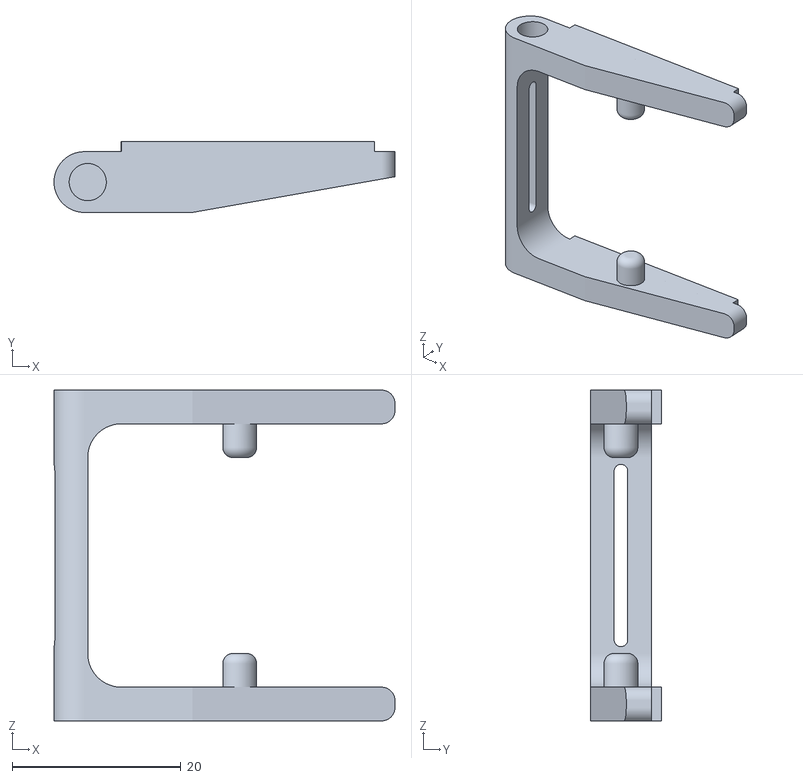
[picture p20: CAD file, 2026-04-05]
3D_models/1x/OWN_01.00.031_display_stand_upper_part.stl
40.4 x 8.40 x 39.2

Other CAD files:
3D_models/1x/OWN_01.00.029_display_stand_middle_part.stl
3D_models/1x/OWN_01.00.026_box_bottom_cover.stl
3D_models/1x/OWN_01.00.024_box_back_cover.stl
3D_models/1x/OWN_01.00.020_box_side_cover.stl
3D_models/1x/EBA_01.00.001.STL
3D_models/1x/EBA_01.00.002_vertical_drive_arm.STL
3D_models/1x/EBA_01.00.004_forward_drive_arm.STL
3D_models/1x/EBA_01.00.005_horizontal_arm.STL
3D_models/1x/EBA_01.00.006_triangular_link.STL
3D_models/1x/EBA_01.00.010_basement.STL
3D_models/1x/EBA_01.00.011_round_plate.STL
3D_models/1x/EBA_01.00.012_R01_claw_support.STL
3D_models/1x/EBA_01.00.013_R01_right_finger.STL
3D_models/1x/EBA_01.00.014_R01_left_finger.STL
3D_models/1x/EBA_01.00.015_drive_gear.STL
3D_models/1x/EBA_01.00.016_R01_driven_gear.STL
3D_models/1x/EBA_01.00.017_platform.STL
3D_models/1x/EBA_01.00.018_esp32_holder.STL
3D_models/1x/OWN_01.00.019_box_bottom_cover.stl
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

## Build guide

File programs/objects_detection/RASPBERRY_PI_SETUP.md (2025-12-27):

## Raspberry Pi setup:

```
sudo apt install build-essential zlib1g-dev libncurses5-dev libgdbm-dev libnss3-dev libssl-dev libreadline-dev libffi-dev libsqlite3-dev wget libbz2-dev
```

### Python 3.8 and pip installation (if you doesn't have Python installed)

```
wget https://www.python.org/ftp/python/3.8.8/Python-3.8.8.tgz
tar -xf Python-3.8.8.tgz
cd Python-3.8.8
./configure --enable-optimizations
sudo make altinstall
sudo apt install python3-pip
```

### Manipulator code

Download the program .zip-file

```
mkdir path/to/manipulator
unzip path/to/robotic_arm_scripts.zip -d path/to/manipulator
```

### Libraries installation

```
python3 -m venv --system-site-packages myenv
source myenv/bin/activate
sudo apt update
sudo apt install python3-opencv libopencv-dev
```

### Then execute commands below:
```
pip install -r robotic_arm_scripts/hailo_scripts/requirements.txt
```

### OR use:

```
pip install numpy==1.24.4
pip install pyserial==3.5
pip install cvzone==1.6.1
pip install ultralytics==8.2.0
pip install lapx==0.5.2
pip install picamera2==0.3.18
```

### Thonny installation (if you want and if Raspberry Pi doesn't contain it)

```
sudo pip install thonny
```

### VS Code installation (if you want, you can use VS Code instead of Thonny)

Download your version here (.deb for Ubuntu and Debian, .rpm for Red Head and Fedora):
https://code.visualstudio.com/ (code_1.85.1-1702462158_amd64.deb in my case)

```
sudo dpkg -i code_1.85.1-1702462158_amd64.deb
sudo apt-get install -f
code
```

Download the python package in VS Code and open the "robotic_arm_scripts" folder in it

Press Ctrl+Shift+P, choose "Select Interpreter", then choose environment

### (DEPRECATED) Dotnet installation (only if you are using TCP/IP communication, not through the Telegram)

Download the version of dotnet for your system to ~/Downloads (for example): https://dotnet.microsoft.com/download/dotnet/8.0
(in my case Arm64 binaries (dotnet-sdk-8.0.201-linux-arm64.tar.gz))

```
mkdir path/to/dotnet-core
tar zxf ~/Downloads/dotnet-sdk-3.1.426-linux-x64.tar.gz -C path/to/dotnet-core
export PATH=$PATH:path/to/dotnet-core
source ~/.bashrc
dotnet --version
```

If the console prints the dotnet version, everything is fine

And then you can build and run your code

### Code execution

```
source myenv/bin/activate
cd path/to/robotic_arm_scripts
python3 hailo_remote_detection.py
```

You can create a desktop icon by following these instructions:

1)
```
nano path/to/run_remote.sh
```
2) Inside this file enter:

```
#!/bin/bash
cd ~/path/to/hailo_scripts
source venv_hailo/bin/activate
source setup_env.sh
cd ..
export TELEGRAM_SENDER_BOT_TOKEN="your_token"
python hailo_remote_detection.py -i rpi -u --hef models/dataset_v5_models/hailo_models/own_yolov8m_lca_light_v2_quantized_model.hef --labels-json hailo_scripts/labels.json
```

3) ```chmod +x path/to/run_commands.sh```
4) ```nano path/to/run_commands.desktop```
5) Inside this file enter:

```
[Desktop Entry]
Type=Application
Name=Run Remote
Icon=utilities-terminal
Exec=/path/to/run_remote.sh
Terminal=true
```

### Transferring data from the Raspberry Pi to your local device

```
scp path_from user_name@rpi_ip_address:path_to
```

### Connecting with VNC

```
ssh user@ip_address -> enter "yes"
sudo raspi-config -> Interface Options -> VNC -> yes
sudo raspi-config -> System options -> Boot / Auto login -> Desktop Autologin
Finish -> yes
```

### Camera rotation

```
sudo nano /boot/firmware/config.txt
dtoverlay=ov5647,rotation=180 # ov5647 is your camera's name
```

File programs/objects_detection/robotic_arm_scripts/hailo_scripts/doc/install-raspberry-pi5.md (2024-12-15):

# How to Set Up Raspberry Pi 5 and Hailo

In this guide, you will learn how to set up the Raspberry Pi 5 with a Hailo-8/8L AI accelerator.

## Table of Contents
- [What You'll Need](#what-youll-need)
- [Hardware](#hardware)
- [Software](#software)
- [Troubleshooting](#troubleshooting)

## What You'll Need
- Raspberry Pi 5 (8GB recommended)
- Raspberry Pi 5 AI KIT (option 1)
  - Raspberry Pi M.2 M-Key HAT
  - Hailo-8L M.2 M-Key module (Hailo-8 is also supported)
- Raspberry Pi 5 AI HAT (option 2)
  - 26TOPs and 13TOPs are supported
- Active Cooler for the Raspberry Pi 5
- Optional: Heat sink
- Optional: An official Raspberry Pi camera (e.g., Camera Module 3 or High-Quality Camera)
- Optional: USB camera

## Hardware
For this guide, we used the Raspberry Pi 5 model along with the official Active Cooler and a 27W USB-C Power Supply. We recommend using the official USB-C power supply to ensure the board can adequately power the M.2 HAT.

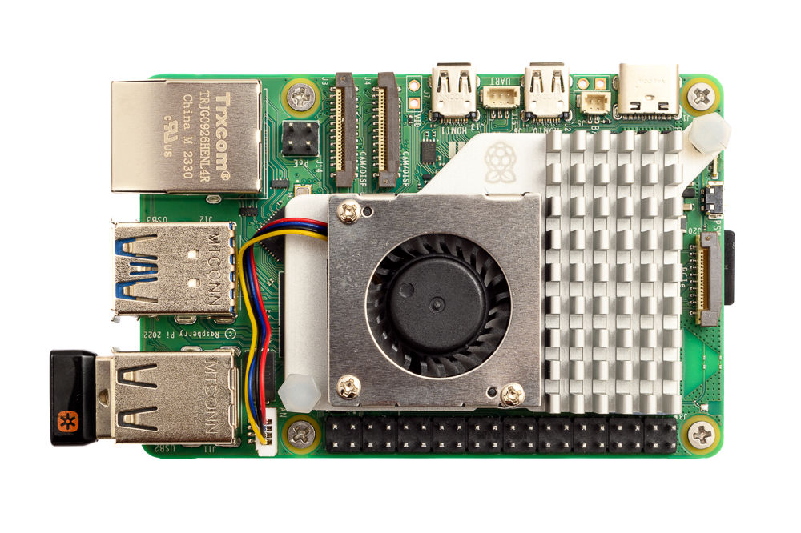
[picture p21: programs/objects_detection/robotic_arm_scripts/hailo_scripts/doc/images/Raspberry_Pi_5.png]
Raspberry Pi 5


### Raspberry Pi M.2 M-Key HAT
The Raspberry Pi M.2 M-Key HAT can be used with the Hailo-8L M.2 key M or B+M. (Hailo-8 is also supported).
When installing the M.2 module, make sure to use the thermal pad to ensure proper heat dissipation between the M.2 module and the HAT.
If your project is encapsulated in a case, make sure to have proper ventilation to avoid overheating. If required, add a heat sink to the Hailo-8L module.
For detailed instructions on how to install the M.2 module, follow [Raspberry Pi's official AI Kit Guide](https://www.raspberrypi.com/documentation/accessories/ai-kit.html#ai-kit).

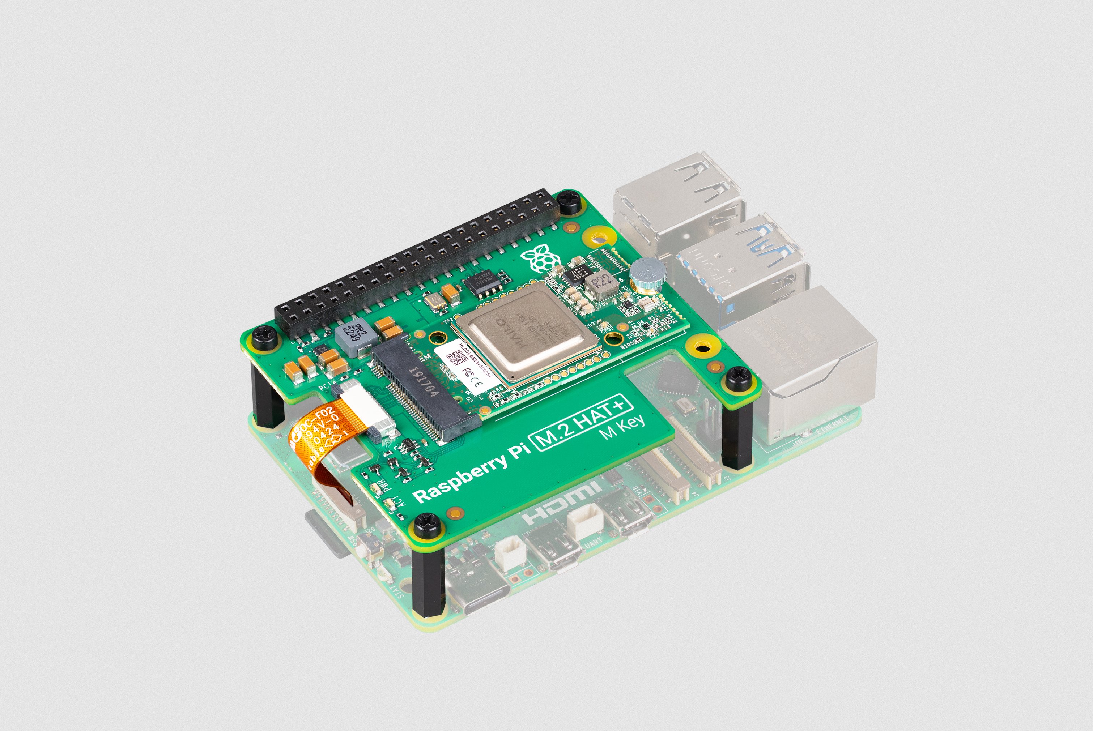
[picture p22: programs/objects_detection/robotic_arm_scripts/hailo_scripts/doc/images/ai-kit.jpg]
Raspberry Pi AI Kit


### Raspberry Pi AI HAT
The Raspberry Pi AI HAT is a standalone board that includes the Hailo-8L AI accelerator. It is a plug-and-play solution that can be used with the Raspberry Pi 5.
When using the AI HAT, make sure to have proper ventilation to avoid overheating. If required, add a heat sink to the Hailo-8 module.
[Raspberry Pi's official AI HAT Guide](https://www.raspberrypi.com/documentation/accessories/ai-hat-plus.html#ai-hat-plus).
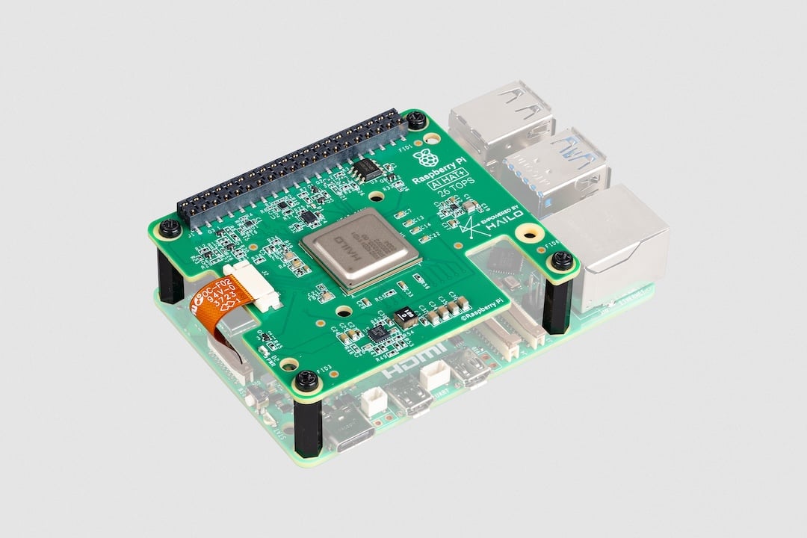
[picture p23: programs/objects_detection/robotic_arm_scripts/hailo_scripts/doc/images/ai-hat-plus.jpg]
Raspberry Pi AI HAT


### Raspberry Pi Camera
See the [Raspberry Pi Camera Guide](https://www.raspberrypi.com/documentation/accessories/camera.html#install-a-raspberry-pi-camera) for instructions on how to install the camera.

## Software

### Install Raspberry Pi OS
Download and install the latest Raspberry Pi Imager for your OS (Windows, macOS, or Ubuntu) from [here](https://www.raspberrypi.com/software/).

Select the Raspberry Pi 5.

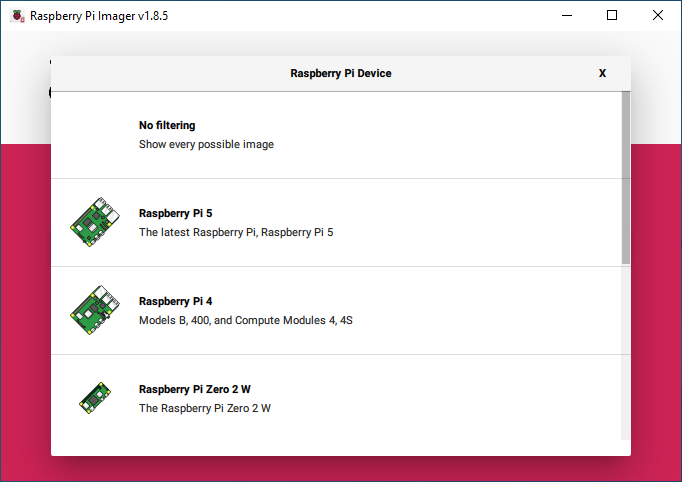
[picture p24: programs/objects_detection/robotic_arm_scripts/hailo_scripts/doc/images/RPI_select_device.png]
Raspberry Pi Imager Select Device


Select Raspberry Pi OS (64-bit).

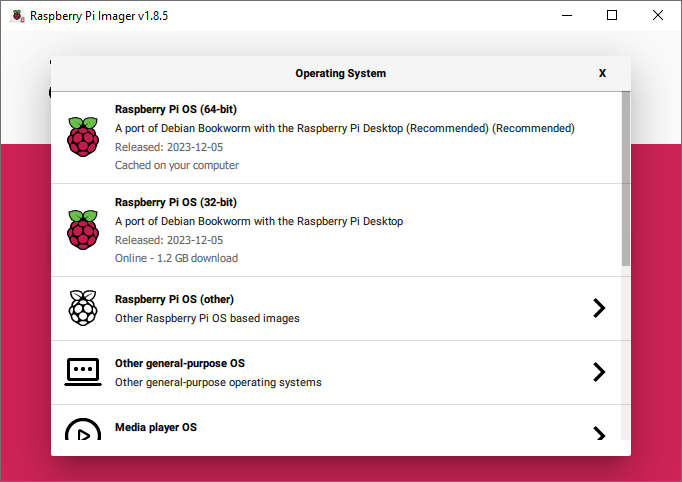
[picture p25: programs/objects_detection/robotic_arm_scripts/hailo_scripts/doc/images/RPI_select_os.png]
Raspberry Pi Imager Select OS


### Update System
Boot up your Raspberry Pi 5 to a graphical environment and update your base software. To do this, open a terminal window and run:
```bash
sudo apt update
sudo apt full-upgrade
```
This will update your system to the latest Raspberry Pi kernel, which includes Hailo driver support.
If you get errors from the `apt full-upgrade` command try running this and retry.
```bash
sudo apt --fix-broken install
```

### Set PCIe to Gen3
To achieve optimal performance from the Hailo device, it is necessary to set PCIe to Gen3. While using Gen2 is an option, it will result in lower performance.

Open the Raspberry Pi configuration tool:
```bash
sudo raspi-config
```
Select option "6 Advanced Options", then select option "A8 PCIe Speed". Choose "Yes" to enable PCIe Gen 3 mode. Click "Finish" to exit.
##### Reboot your Raspberry Pi.
```bash
sudo reboot
```

### Install Hailo Software
Install all the necessary software to get the Raspberry Pi AI Kit working. To do this, run the following command from a terminal window:
```bash
sudo apt install hailo-all
```
This will install the following software components:
- Hailo firmware
- HailoRT runtime software. See [HailoRT GitHub Repo](https://github.com/hailo-ai/hailort) for more information.
- Hailo TAPPAS Core package: A derivative of the TAPPAS repository, this core package includes GStreamer elements, post-processing functions, and additional tools used by this repository. It is essential for developing applications on the Pi but does not include standalone applications. See [Hailo TAPPAS GitHub](https://github.com/hailo-ai/tappas) for more information and documentation.
- The `rpicam-apps` Hailo post-processing software demo stages. See [Raspberry Pi Official Examples](../README.md#raspberry-pi-official-examples) for more information.

##### Reboot your Raspberry Pi.
```bash
sudo reboot
```

### Verify Installation
Now you can check if the Hailo chip is recognized by the system:
```bash
hailortcli fw-control identify
```
If everything is OK, it should output something like this:
```bash
Executing on device: 0000:01:00.0
Identifying board
Control Protocol Version: 2
Firmware Version: 4.17.0 (release,app,extended context switch buffer)
Logger Version: 0
Board Name: Hailo-8
Device Architecture: HAILO8L
Serial Number: HLDDLBB234500128
Part Number: HM21LB1C2LAE
Product Name: HAILO-8L AI ACC M.2 B+M KEY MODULE EXT TMP
```
If you don't see this output, check the [PCIe troubleshooting](#pcie-troubleshooting) section.

#### Test TAPPAS Core installation by running the following commands:

Hailotools: (TAPPAS Gstreamer elements)
```bash
gst-inspect-1.0 hailotools
```
expected result:
```
Plugin Details:
  Name                     hailotools
  Description              hailo tools plugin
  Filename                 /lib/aarch64-linux-gnu/gstreamer-1.0/libgsthailotools.so
  Version                  3.28.2
  License                  unknown
  Source module            gst-hailo-tools
  Binary package           gst-hailo-tools
  Origin URL               https://hailo.ai/

  hailoaggregator: hailoaggregator - Cascading
  hailocounter: hailocounter - postprocessing element
  hailocropper: hailocropper
  hailoexportfile: hailoexportfile - export element
  hailoexportzmq: hailoexportzmq - export element
  hailofilter: hailofilter - postprocessing element
  hailogallery: Hailo gallery element
  hailograytonv12: hailograytonv12 - postprocessing element
  hailoimportzmq: hailoimportzmq - import element
  hailomuxer: Muxer pipeline merging
  hailonv12togray: hailonv12togray - postprocessing element
  hailonvalve: HailoNValve element
```

Hailonet: (HailoRT inference Gstreamer element)
```bash
gst-inspect-1.0 hailo
```
expected result:
```
Plugin Details:
  Name                     hailo
  Description              hailo gstreamer plugin
  Filename                 /lib/aarch64-linux-gnu/gstreamer-1.0/libgsthailo.so
  Version                  1.0
  License                  unknown
  Source module            hailo
  Binary package           GStreamer
  Origin URL               http://gstreamer.net/

  hailodevicestats: hailodevicestats element
  hailonet: hailonet element
  synchailonet: sync hailonet element

  3 features:
  +-- 3 elements
```
If `hailo` or `hailotools` are not found, try deleting the GStreamer registry:
```bash
rm ~/.cache/gstreamer-1.0/registry.aarch64.bin
```
##### If everything is OK you can continue installing the [hailo_rpi5_examples.](../README.md#configure-environment)

## Upgrade or Downgrade Hailo Software
To upgrade to the latest version of the Hailo software package, run the following commands:
```bash
sudo apt update
sudo apt full-upgrade
sudo apt install hailo-all
sudo reboot
```
Don't forget to update our GitHub repository to the latest version to get the latest examples and resources.
```bash
cd [your-path]/hailo-rpi5-examples
git pull
```

To downgrade to a previous version (TAPPAS 3.28.2), run the following commands:
```bash
sudo apt install hailort=4.17.0 hailo-tappas-core-3.28.2 hailofw=4.17.0-2 hailo-dkms=4.17.0-1
sudo reboot
```

## Troubleshooting
Got a question? Join the discussion on [Hailo Community Forum](https://community.hailo.ai/).
### PCIe Troubleshooting
Make sure the PCIe board and the M.2 module are properly connected. To test if the PCIe board is recognized by the system, run the following command:
```bash
lspci | grep Hailo
```
If you get output like:
```bash
0000:01:00.0 Co-processor: Hailo Technologies Ltd. Hailo-8 AI Processor (rev 01)
```
Then the PCIe board is recognized by the system. If not, check the connection, power supply, and make sure PCIe is enabled (see Raspberry Pi documentation). If the board is new, you may need to update the firmware of the Raspberry Pi 5.

### Driver Issue
If you get an error saying the Hailo driver is not installed, make sure your kernel version is greater than 6.6.31. You can get the kernel version by running:
```bash
uname -a
```
If the kernel version is lower than 6.6.31, you may need to run `apt update` and `apt full-upgrade` to update the kernel. If your kernel version is OK, reboot the system and try again.

## Known Issues
The issues below should be handled by the TAPPAS Core installation deb, but if you encounter them, you can fix them manually.

### PCIe Page Size Issue
Some hosts do not support certain PCIe descriptor page sizes. If you get an error like this:
```bash
[HailoRT] [error] CHECK_AS_EXPECTED failed - max_desc_page_size given 16384 is bigger than hw max desc page size 4096
```
Make sure the `/etc/modprobe.d/hailo_pci.conf` exists and contains the following line:
```bash
options hailo_pci force_desc_page_size=4096
```
Check the configuration:
```bash
cat /etc/modprobe.d/hailo_pci.conf
# expected result:
options hailo_pci force_desc_page_size=4096
```

### Cannot Allocate Memory in Static TLS Block
In some scenarios (especially aarch64), you might experience the following error causing some GStreamer plugins to not load correctly. The error message is:
```

bash
(gst-plugin-scanner:67): GStreamer-WARNING **: 12:20:39.178: Failed to load plugin '/usr/lib/aarch64-linux-gnu/gstreamer-1.0/libgstlibav.so': /lib/aarch64-linux-gnu/libgomp.so.1: cannot allocate memory in static TLS block
```
This issue should be fixed by adding this to your `.bashrc` file:
```bash
echo 'export LD_PRELOAD=/usr/lib/aarch64-linux-gnu/libgomp.so.1' >> ~/.bashrc
```
If you already encountered this error, you can fix it by running the following commands:
```bash
export LD_PRELOAD=/usr/lib/aarch64-linux-gnu/libgomp.so.1
rm ~/.cache/gstreamer-1.0/registry.aarch64.bin
```

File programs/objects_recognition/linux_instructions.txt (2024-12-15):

sudo apt install build-essential zlib1g-dev libncurses5-dev libgdbm-dev libnss3-dev libssl-dev libreadline-dev libffi-dev libsqlite3-dev wget libbz2-dev

----- Python 3.8 and pip installation ----- (if you doesn't have Python installed)

wget https://www.python.org/ftp/python/3.8.8/Python-3.8.8.tgz

tar -xf Python-3.8.8.tgz
cd Python-3.8.8
./configure --enable-optimizations
sudo make altinstall
sudo apt install python3-pip

----- Program -----

Download the program .zip-file

mkdir ~/manipulator
unzip ~/Downloads/yolov8_recognizer_manipulator.zip -d ~/manipulator

----- Libraries installation -----

python3 -m venv --system-site-packages myenv
source myenv/bin/activate
sudo apt update
sudo apt install python3-opencv libopencv-dev

Then manually execute commands below or use:
pip install -r yolov8_recognizer_manipulator/requirements/requirements.txt

pip install numpy==1.24.4
pip install pyserial==3.5
pip install cvzone==1.6.1
pip install ultralytics==8.2.0
pip install lapx==0.5.2
pip install picamera2==0.3.18

----- Thonny installation ----- (if you want and if Raspberry Pi doesn't contain it)

sudo pip install thonny

----- VS Code installation ----- (if you want, you can use VS Code instead of Thonny)

Download your version here (.deb for Ubuntu and Debian, .rpm for Red Head and Fedora):
https://code.visualstudio.com/ (code_1.85.1-1702462158_amd64.deb in my case)

sudo dpkg -i code_1.85.1-1702462158_amd64.deb
sudo apt-get install -f
code

Download the python package in VS Code and open the "yolov8_recognizer_manipulator" folder in it

Press Ctrl+Shift+P, choose "Select Interpreter", then choose environment

----- Dotnet installation -----

Download the version of dotnet for your system to ~/Downloads: https://dotnet.microsoft.com/download/dotnet/8.0
(in my case Arm64 binaries (dotnet-sdk-8.0.201-linux-arm64.tar.gz))

mkdir ~/dotnet-core
tar zxf ~/Downloads/dotnet-sdk-3.1.426-linux-x64.tar.gz -C ~/dotnet-core
export PATH=$PATH:~/dotnet-core
source ~/.bashrc
dotnet --version

If the console print out the version of dotnet, everything is fine

And then you can build and run your code

----- Code execution -----

source myenv/bin/activate
cd /home/olegqm/manipulator/yolov8_recognizer_manipulator
python3 yolov8_recognizer_manipulator.py

You can create desctop icon with this commands by following this istructions:

1) nano ~/Desktop/run_commands.sh
2) Inside this file enter:

#!/bin/bash
source myenv/bin/activate
cd /home/olegqm/manipulator/yolov8_recognizer_manipulator
python3 yolov8_recognizer_manipulator.py

3) chmod +x ~/Desktop/run_commands.sh
4) nano ~/Desktop/run_commands.desktop
5) Inside this file enter:

[Desktop Entry]
Type=Application
Name=Run Commands
Icon=utilities-terminal
Exec=/home/olegqm/Desktop/run_commands.sh
Terminal=true

----- Transfering data -----

scp path_from user_name@rpi_ip_address:path_to

----- Connecting with VNC -----

ssh user@ip_address -> enter "yes"
sudo raspi-config -> Interface Options -> VNC -> yes
sudo raspi-config -> System options -> Boot / Auto login -> Desktop Autologin
Finish -> yes

----- Camera rotation -----

sudo nano /boot/firmware/config.txt
dtoverlay=ov5647,rotation=180 # ov5647 is your camera's name

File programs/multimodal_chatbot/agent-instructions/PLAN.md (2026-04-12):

# Multimodal Chatbot — Implementation Plan

> **Status**: Implementation complete. All 27 tests passing. Docker Compose verified locally.  
> **Last updated**: 2026-03-08

---

## TL;DR

Build a multimodal chatbot REST API (**FastAPI + LangGraph + OpenAI GPT-5-mini**) that:
- accepts images (base64) + text questions from a mobile app
- stores per-session chat history in **Redis**
- auto-cleans up expired sessions (cron every 10 min, 1h TTL)
- checks token limits via `tiktoken` (HTTP 409 if context window exceeded)
- runs in **Docker** with **Nginx basic auth** in front
- deploys to AWS EC2 via **GitHub Actions** CI/CD

---

## Decisions

| Concern | Decision |
|---|---|
| LLM | OpenAI GPT-5-mini (multimodal: vision + text) |
| Agent framework | LangGraph `StateGraph` (full agent, not a plain API call) |
| Agent tools (v1) | `analyze_image` — vision tool (expandable later) |
| API interface | REST only |
| Session storage | Redis (sessions survive restarts until TTL expires) |
| Session lifecycle | Created via endpoint; deleted via endpoint **or** auto-cleanup |
| Session TTL | 1 hour of inactivity |
| Cleanup interval | Every 10 minutes |
| Token limit | tiktoken; HTTP 409 if exceeded → client must recreate chat |
| Auth | Nginx basic auth, credentials in `.env` / GitHub Secrets |
| TLS / DNS | Not required — plain HTTP only |

---

## Target Project Structure

```
programs/multimodal_chatbot/
├── docker-compose.yaml              # top-level, single 'docker compose up' command
├── pytest.ini                       # pytest configuration
├── .env                             # secrets (never committed)
├── .env.example                     # template with placeholder values
├── README.md                        # project overview + quick start
│
├── agent-instructions/
│   ├── PLAN.md                      # ← this file
│   ├── architecture/
│   │   └── overview.md              # tech stack, data flow diagram
│   ├── api/
│   │   └── endpoints.md             # full API reference with examples
│   └── deployment/
│       └── server-setup.md          # EC2 setup, GitHub Secrets, deployment guide
│
├── app/
│   ├── Dockerfile                   # Python 3.12-slim app image
│   ├── requirements.txt             # runtime Python dependencies
│   ├── __init__.py
│   ├── main.py                      # FastAPI app, lifespan, middleware, router mount
│   ├── config.py                    # Pydantic BaseSettings (all env vars)
│   ├── models/
│   │   ├── __init__.py
│   │   ├── chat.py                  # ChatRequest, ChatResponse, TokenLimitError
│   │   └── session.py               # SessionCreate, SessionResponse, SessionDeleteResponse
│   ├── routers/
│   │   ├── __init__.py
│   │   ├── chat.py                  # POST /api/v1/chat
│   │   ├── session.py               # CRUD /api/v1/sessions
│   │   └── health.py                # GET /health
│   ├── services/
│   │   ├── __init__.py
│   │   ├── agent.py                 # LangGraph StateGraph agent
│   │   ├── session_manager.py       # Redis session CRUD + tiktoken token counting
│   │   └── cleanup.py               # APScheduler background cleanup task
│   └── tools/
│       ├── __init__.py
│       └── image_analysis.py        # LangGraph @tool: analyze image via vision
│
├── nginx/
│   ├── nginx.conf                   # reverse proxy + basic auth config
│   ├── Dockerfile                   # nginx:alpine + apache2-utils
│   └── entrypoint.sh                # generate .htpasswd from env vars at startup
│
└── tests/
    ├── Dockerfile                   # Python 3.12-slim test runner image
    ├── requirements.txt             # test dependencies (references app/requirements.txt)
    ├── __init__.py
    ├── conftest.py                  # fixtures: fakeredis, async test client
    ├── test_health.py
    ├── test_session.py
    └── test_chat.py
```

---

## Phase 1 — Project Scaffold & Configuration

### Step 1.1 — Directory tree
Create all directories and empty `__init__.py` files listed above.

### Step 1.2 — `app/config.py` (Pydantic BaseSettings)
Environment variables exposed via `Settings`:

| Variable | Default | Description |
|---|---|---|
| `OPENAI_API_KEY` | — | OpenAI secret key |
| `OPENAI_MODEL` | `gpt-4o-mini` | Model name (change to `gpt-5-mini` when available) |
| `REDIS_URL` | `redis://redis:6379/0` | Redis connection string |
| `SESSION_TTL_SECONDS` | `3600` | Inactivity TTL for auto-cleanup |
| `CLEANUP_INTERVAL_SECONDS` | `600` | How often to run cleanup (10 min) |
| `MAX_CONTEXT_TOKENS` | `100000` | Model context window limit |
| `BASIC_AUTH_USER` | — | Nginx basic auth username |
| `BASIC_AUTH_PASSWORD` | — | Nginx basic auth password |
| `LOG_LEVEL` | `INFO` | Logging level |

### Step 1.3 — Secrets files
- `.env` — real values (not committed to git)
- `.env.example` — placeholders documenting required variables
- `.gitignore` — ensure `.env` is listed

---

## Phase 2 — Data Models & Session Management

### Step 2.1 — Pydantic models (`app/models/`)

**`chat.py`**:
- `ChatRequest`: `session_id: str`, `message: str`, `image: Optional[str]` (base64), `image_url: Optional[str]`
- `ChatResponse`: `session_id: str`, `response: str`, `tokens_used: int`, `tokens_remaining: int`
- `TokenLimitExceededResponse`: `session_id: str`, `error: str`, `action: Literal["recreate_session"]`

**`session.py`**:
- `SessionCreateResponse`: `session_id: str`, `created_at: datetime`
- `SessionInfoResponse`: `session_id: str`, `created_at: datetime`, `last_activity: datetime`, `message_count: int`
- `SessionDeleteResponse`: `session_id: str`, `deleted: bool`
- `ChatMessageRecord`: `role: str`, `content: str`, `has_image: bool`, `image_id: Optional[str]`, `timestamp: datetime`

### Step 2.2 — Redis session service (`app/services/session_manager.py`)

Redis key schema:
- `session:{id}:meta` — hash: `created_at`, `last_activity`
- `session:{id}:messages` — list of JSON-serialized message objects

Methods:
- `create_session() -> str` — generate UUID4, store meta hash
- `session_exists(session_id) -> bool`
- `get_session_info(session_id) -> SessionInfoResponse`
- `add_message(session_id, role, content, has_image=False, image_id=None) -> None` — append to list, update `last_activity`
- `get_history(session_id) -> list[ChatMessageRecord]`
- `store_image(session_id, image_b64) -> str` — store image in Redis and return `image_id`
- `get_image(session_id, image_id) -> Optional[str]`
- `count_tokens(session_id) -> int` — tiktoken encode full conversation
- `check_token_limit(session_id) -> bool` — True if within `MAX_CONTEXT_TOKENS`
- `delete_session(session_id) -> bool`
- `get_all_session_ids() -> list[str]` — for cleanup scanning

### Step 2.3 — Cleanup task (`app/services/cleanup.py`)
- Uses `apscheduler` `AsyncIOScheduler` started in FastAPI lifespan
- Job runs every `CLEANUP_INTERVAL_SECONDS`
- Scans all sessions, deletes those where `now - last_activity > SESSION_TTL_SECONDS`
- Logs number of cleaned sessions

---

## Phase 3 — LangGraph Agent *(parallel with Phase 2)*

### Step 3.1 — Image analysis tool (`app/tools/image_analysis.py`)
```python
@tool
def analyze_image(image_base64: str, question: str) -> str:
    """Analyze an image and answer a specific question about it."""
```
- Constructs a vision-enabled OpenAI message with base64 image content part
- Returns a descriptive string answer

### Step 3.2 — Agent graph (`app/services/agent.py`)

LangGraph `StateGraph` structure:
```
[user message] → agent node → (tool call?) → tools node → agent node → ... → END
```

State:
```python
class AgentState(TypedDict):
    messages: list[BaseMessage]
```

Flow:
- `agent` node: call `ChatOpenAI` with bound tools
- conditional edge: if last message is `ToolMessage` candidate → route to `tools`, else → `END`
- `tools` node: `ToolNode` from langgraph prebuilt

Public function:
```python
async def invoke_agent(
    settings: Settings,
    history: list[ChatMessageRecord],
    user_message: str,
    session_id: str,
    image_id: Optional[str] = None,
    image_url: Optional[str] = None,
) -> str
```

---

## Phase 4 — API Routers *(depends on Phase 2 + 3)*

### `GET /health`
Returns:
```json
{"status": "ok", "redis": "connected"}
```
Returns `503` if Redis is unreachable.

### `POST /api/v1/sessions`
Creates new session. Returns `SessionCreateResponse`.

### `GET /api/v1/sessions/{session_id}`
Returns `SessionInfoResponse` or `404`.

### `GET /api/v1/sessions/{session_id}/history`
Returns list of `ChatMessageRecord` or `404`.

### `DELETE /api/v1/sessions/{session_id}`
Deletes session. Returns `SessionDeleteResponse`.

### `POST /api/v1/chat`
**Request**: `ChatRequest`  
Client sends only `session_id`, current `message`, and optional `image` or `image_url`.
The service loads prior conversation history from Redis by `session_id`; clients do not
send history in the request body.

**Flow**:
1. Validate session exists → `404` if not
2. Check token limit → `409 TokenLimitExceededResponse` if exceeded
3. Store image in Redis if present
4. Store user message in Redis
5. Load session history from Redis and invoke LangGraph agent with it
6. Store assistant response in Redis
7. Return `ChatResponse` with token stats

---

## Phase 5 — Docker & Nginx *(depends on Phase 4)*

### `app/Dockerfile`
```dockerfile
FROM python:3.12-slim
WORKDIR /app
COPY app/requirements.txt app/requirements.txt
RUN pip install --no-cache-dir -r app/requirements.txt
COPY app/ app/
CMD ["uvicorn", "app.main:app", "--host", "0.0.0.0", "--port", "8000"]
```

### `nginx/nginx.conf`
- Listen port 80
- `auth_basic` with `/etc/nginx/.htpasswd`
- `proxy_pass http://app:8000`
- `client_max_body_size 20M` (for image uploads)

### `nginx/entrypoint.sh`
```bash
htpasswd -bc /etc/nginx/.htpasswd "$BASIC_AUTH_USER" "$BASIC_AUTH_PASSWORD"
exec nginx -g 'daemon off;'
```

### `docker-compose.yaml`
Four services (tests via `--profile test`):
- **app** — builds from repo root (`dockerfile: app/Dockerfile`), internal port 8000, `env_file: .env`, depends_on redis
- **redis** — `redis:7-alpine`, named volume `redis_data`, internal 6379, healthcheck
- **nginx** — builds from `nginx/`, ports `"80:80"`, env `BASIC_AUTH_USER` + `BASIC_AUTH_PASSWORD`, depends_on app
- **tests** — builds from repo root (`dockerfile: tests/Dockerfile`), own `tests/requirements.txt`, profile `test`, depends_on redis

---

## Phase 6 — Testing *(depends on Phase 5)*

Tests run inside a dedicated Docker container (`tests` service with `--profile test`).  
Each container has its own `requirements.txt`:
- `app/requirements.txt` — runtime dependencies
- `tests/requirements.txt` — test dependencies, references `app/requirements.txt` via `-r`

Run tests: `docker compose --profile test run --rm tests`

### `tests/conftest.py`
- `fakeredis` async server fixture replacing real Redis
- `AsyncClient` fixture for FastAPI test client

### Test scenarios

| Test | Description |
|---|---|
| Health OK | `GET /health` → 200 |
| Health Redis down | Redis unavailable → 503 |
| Create session | `POST /api/v1/sessions` → 201, return `session_id` |
| Get session | `GET /api/v1/sessions/{id}` → 200 |
| Delete session | `DELETE /api/v1/sessions/{id}` → 200; subsequent GET → 404 |
| Chat text-only | `POST /api/v1/chat` with message only → 200, non-empty response |
| Chat with image | `POST /api/v1/chat` with base64 image → 200, image-related response |
| Token limit | Simulate full context → 409 with `action: "recreate_session"` |
| Cleanup task | Inject expired session, run cleanup, verify deleted |

---

## Phase 7 — CI/CD & Deployment *(depends on Phase 6)*

### `.github/workflows/deploy.yml`

```
Trigger: push to main (paths: programs/multimodal_chatbot/**)

Jobs:
  test:
    - Spin up Redis service container
    - Install dependencies
    - Run pytest

  deploy (needs: test):
    - SSH to 35.156.245.59 (ubuntu)
    - cd /home/ubuntu/multimodal_chatbot
    - git pull
    - Write .env from GitHub Secrets
    - docker compose down && docker compose up -d --build
```

### Required GitHub Secrets

| Secret | Value source |
|---|---|
| `OPENAI_API_KEY` | OpenAI dashboard |
| `BASIC_AUTH_USER` | From `.env` |
| `BASIC_AUTH_PASSWORD` | From `.env` |
| `SSH_PRIVATE_KEY` | Contents of `/home/olegqm/aws_ssh_keys/robotic-arm-chatbot/robotic-arm-ssh-key.pem` |
| `SERVER_HOST` | `35.156.245.59` |
| `SERVER_USER` | `ubuntu` |

---

## Phase 8 — Documentation *(finalized last)*

- `agent-instructions/architecture/overview.md` — architecture diagram + data flow
- `agent-instructions/api/endpoints.md` — full API reference
- `agent-instructions/deployment/server-setup.md` — EC2 prerequisites + step-by-step deploy
- `README.md` — project overview, quick start, env vars table, example API calls

---

## Implementation Order

```
Phase 1 (scaffold, config)
    ↓
Phase 2 (models, Redis service) ──── [parallel] ──── Phase 3 (LangGraph agent)
    ↓                                                      ↓
    └──────────────── Phase 4 (API routers) ───────────────┘
                            ↓
                     Phase 5 (Docker, Nginx)
                            ↓
                      Phase 6 (tests)
                            ↓
                    Phase 7 (CI/CD, deploy)
                            ↓
                  Phase 8 (docs finalize)
```

---

## Final Verification Checklist

- [ ] `docker compose --profile test run --rm tests` — all 27 tests pass in container
- [ ] `docker compose up --build` — all 3 services start without errors
- [ ] `curl -u <user>:<pass> http://localhost/health` → `{"status":"ok","redis":"connected"}`
- [ ] Create session → chat (text) → chat (image+text) → get history → delete session
- [ ] Fill context → receive HTTP 409 with `"action": "recreate_session"`
- [ ] Push to `main` → GitHub Action passes → SSH deploy succeeds
- [ ] `curl -u <user>:<pass> http://35.156.245.59/health` → 200 OK

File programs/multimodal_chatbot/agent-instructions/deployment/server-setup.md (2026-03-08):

# Server Setup & Deployment Guide

## EC2 Server Details

| Parameter | Value |
|---|---|
| Host | `35.156.245.59` |
| User | `ubuntu` |
| SSH Key | `/home/olegqm/aws_ssh_keys/robotic-arm-chatbot/robotic-arm-ssh-key.pem` |
| Application path | `/home/ubuntu/multimodal_chatbot/` |
| Exposed port | `80` (HTTP) |

## Prerequisites on Server

1. **Docker** and **Docker Compose** must be installed:
   ```bash
   sudo apt update
   sudo apt install -y docker.io docker-compose-plugin
   sudo usermod -aG docker ubuntu
   ```

2. **Firewall / Security Group** must allow inbound traffic on port 80 (HTTP).

3. **Disk space**: at least 5 GB free for Docker images and Redis data.

## Manual Deployment

```bash
# SSH to server
ssh -i /home/olegqm/aws_ssh_keys/robotic-arm-chatbot/robotic-arm-ssh-key.pem ubuntu@35.156.245.59

# Navigate to project
cd /home/ubuntu/multimodal_chatbot

# Ensure .env is present with correct values
cat .env

# Build and start
docker compose up -d --build

# Check logs
docker compose logs -f

# Check health
curl http://localhost/health
```

## Automated Deployment (GitHub Actions)

The workflow at `.github/workflows/deploy.yml` automatically:

1. Runs `pytest` on every push to `main` (if `programs/multimodal_chatbot/**` changed)
2. If tests pass, SSHes to the EC2 server and:
   - Syncs project files via `rsync`
   - Writes `.env` from GitHub Secrets
   - Runs `docker compose down && docker compose up -d --build`

### Required GitHub Secrets

| Secret | Description |
|---|---|
| `SSH_PRIVATE_KEY` | Contents of the `.pem` SSH key file |
| `SERVER_HOST` | `35.156.245.59` |
| `SERVER_USER` | `ubuntu` |
| `OPENAI_API_KEY` | OpenAI API key |
| `BASIC_AUTH_USER` | Username for Nginx basic auth |
| `BASIC_AUTH_PASSWORD` | Password for Nginx basic auth |

### Setting up GitHub Secrets

```bash
# Read the SSH key
cat /home/olegqm/aws_ssh_keys/robotic-arm-chatbot/robotic-arm-ssh-key.pem
```

Then go to **GitHub → Repository → Settings → Secrets and variables → Actions** and add each secret listed above.

## Troubleshooting

### Containers won't start
```bash
docker compose logs app     # Check FastAPI logs
docker compose logs redis   # Check Redis logs
docker compose logs nginx   # Check Nginx logs
```

### Redis connection error
- Verify Redis container is running: `docker compose ps`
- Check Redis health: `docker compose exec redis redis-cli ping`

### Port 80 already in use
```bash
sudo lsof -i :80
sudo systemctl stop apache2   # if Apache is running
```

### Rebuild from scratch
```bash
docker compose down -v        # remove volumes too
docker compose up -d --build
```

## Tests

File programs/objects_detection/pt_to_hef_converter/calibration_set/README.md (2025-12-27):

## 500-1000 images from your real dataset (containing all classes from it).
## You can use copy_calibset_images.py for coping images.

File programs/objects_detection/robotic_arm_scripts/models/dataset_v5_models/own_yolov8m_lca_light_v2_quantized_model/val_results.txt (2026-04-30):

Ultralytics 8.3.100 🚀 Python-3.10.12 torch-2.3.1+cu121 CUDA:0 (NVIDIA GeForce RTX 4070 Laptop GPU, 7940MiB)
YOLOv8m_lca_light_v2 summary (fused): 187 layers, 22,731,456 parameters, 0 gradients, 68.7 GFLOPs
                 Class     Images  Instances      Box(P          R      mAP50  mAP50-95): 100%|██████████| 59/59 [00:38<00:00,  1.55it/s]
                   all       3664       6307      0.931       0.89      0.935       0.750
                 apple        442       1096      0.948      0.908      0.949      0.759
                  bear        218        295      0.941      0.900      0.943      0.753
                  bird        219        323      0.950      0.909      0.951      0.740
                   dog        353       1117      0.949      0.908      0.951      0.761
                  boar        222        363      0.935      0.894      0.937      0.746
                   cat        221        780      0.944      0.903      0.946      0.756
                   cow        220        275      0.938      0.897      0.940      0.749
               raccoon        438        456      0.950      0.909      0.952      0.762
                  deer        223        261      0.929      0.888      0.931      0.743
              elephant        221        337      0.924      0.883      0.926      0.737
              hedgehog        182        191      0.948      0.907      0.950      0.731
                monkey        189        254      0.921      0.880      0.922      0.735
              squirrel        221        247      0.944      0.903      0.946      0.727
                 tiger        221        312      0.937      0.896      0.939      0.750

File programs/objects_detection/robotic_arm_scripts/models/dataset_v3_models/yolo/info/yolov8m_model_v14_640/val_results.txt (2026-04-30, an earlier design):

Ultralytics 8.3.47 🚀 Python-3.10.12 torch-2.1.0+cu121 CUDA:0 (NVIDIA GeForce RTX 4070 Laptop GPU, 7940MiB)
YOLOv8m summary (fused): 169 layers, 25,902,640 parameters, 0 gradients, 79.1 GFLOPs
                 Class     Images  Instances      Box(P          R      mAP50  mAP50-95): 100%|██████████| 58/58 [00:35<00:00,  1.63it/s]
                   all       3664       6307      0.962      0.951      0.962      0.797
                 apple        442       1096      0.978      0.967      0.980      0.823
                  bear        218        295      0.971      0.959      0.973      0.819
                  bird        219        323      0.941      0.927      0.943      0.762
                   dog        353       1117      0.975      0.963      0.976      0.825
                  boar        222        363      0.964      0.951      0.965      0.801
                   cat        221        780      0.973      0.961      0.974      0.820
                   cow        220        275      0.967      0.954      0.968      0.808
               raccoon        438        456      0.979      0.968      0.981      0.826
                  deer        223        261      0.960      0.947      0.961      0.797
              elephant        221        337      0.956      0.943      0.957      0.791
              hedgehog        182        191      0.937      0.924      0.939      0.754
                monkey        189        254      0.951      0.938      0.952      0.787
              squirrel        221        247      0.933      0.920      0.935      0.749
                 tiger        221        312      0.966      0.953      0.967      0.804

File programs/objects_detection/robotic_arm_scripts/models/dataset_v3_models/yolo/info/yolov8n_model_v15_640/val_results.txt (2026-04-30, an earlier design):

Ultralytics 8.3.47 🚀 Python-3.10.12 torch-2.1.0+cu121 CUDA:0 (NVIDIA GeForce RTX 4070 Laptop GPU, 7940MiB)
YOLOv8n summary (fused): 168 layers, 3,157,200 parameters, 0 gradients, 8.9 GFLOPs
                 Class     Images  Instances      Box(P          R      mAP50  mAP50-95): 100%|██████████| 58/58 [00:14<00:00,  4.11it/s]
                   all       3664       6307      0.968      0.942      0.968      0.758
                 apple        442       1096      0.984      0.956      0.984      0.776
                  bear        218        295      0.977      0.949      0.977      0.771
                  bird        219        323      0.945      0.918      0.946      0.723
                   dog        353       1117      0.981      0.953      0.982      0.779
                  boar        222        363      0.970      0.943      0.971      0.762
                   cat        221        780      0.979      0.951      0.979      0.773
                   cow        220        275      0.974      0.946      0.974      0.768
               raccoon        438        456      0.985      0.958      0.985      0.784
                  deer        223        261      0.966      0.939      0.967      0.757
              elephant        221        337      0.962      0.935      0.963      0.751
              hedgehog        182        191      0.941      0.913      0.942      0.714
                monkey        189        254      0.957      0.929      0.957      0.747
              squirrel        221        247      0.937      0.909      0.938      0.710
                 tiger        221        312      0.972      0.944      0.972      0.763

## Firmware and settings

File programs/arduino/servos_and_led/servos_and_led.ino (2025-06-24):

#include <Servo.h>
#define numOfValsRec 3
#define digitsPerValRec 3

Servo servo1;
Servo servo2;
Servo servo3;

const int flashlightPin = 5;

int const STEP = 1;
int angles[] = {20, 60, 90};
int stringLength = numOfValsRec * digitsPerValRec + 1;
int counter = 0;
bool counterStart = false;
String recievedString = "";

void setup() {
  Serial.begin(9600);
  servo1.attach(2);
  servo2.attach(3);
  servo3.attach(4);

  servo1.write(angles[0]);
  servo2.write(angles[1]);
  servo3.write(angles[2]);

  pinMode(flashlightPin, OUTPUT);
  digitalWrite(flashlightPin, LOW);
}

void reciveData() {
  static String input = "";
  while (Serial.available()) {
    char c = Serial.read();
    input += c;
    if (input.endsWith("@ON")) {
      digitalWrite(flashlightPin, HIGH);
      input = "";
    } else if (input.endsWith("@OFF")) {
      digitalWrite(flashlightPin, LOW);
      input = "";
    } 
    else if (input.startsWith("$") && input.length() == stringLength) {
      for (int i = 0; i < 3; ++i) {
        angles[i] = input.substring(1 + i * 3, 1 + (i + 1) * 3).toInt();
      }
      input = "";
    }
    if (input.length() > 20) input = input.substring(input.length() - 20);
  }
}

void writeAngle(Servo serv, int& angle) {
  int passed = 0;
  while(passed < angle) {
    serv.write(STEP);
    passed += STEP;
    delay(5);
  }
}

void loop() {
  reciveData();

  if (angles[0] >= 0 && angles[0] <= 60) {
    servo1.write(angles[0]);
  }
    //writeAngle(servo1, angles[0]);
  if (angles[1] >= 50 && angles[1] <= 180) {
    servo2.write(angles[1]);
  }
    //writeAngle(servo2, angles[1]);
  if (angles[2] >= 0 && angles[2] <= 180) { 
    servo3.write(angles[2]);
  }
    //writeAngle(servo3, angles[2]);
}

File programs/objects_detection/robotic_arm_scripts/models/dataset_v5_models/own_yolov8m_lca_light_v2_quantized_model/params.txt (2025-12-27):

train_args = dict(
    imgsz=640,
    epochs=300,
    batch=12,
    workers=8,
    device=device,

    optimizer="AdamW",
    lr0=0.002,
    cos_lr=True,
    lrf=0.05,

    weight_decay=5e-3,

    box=7.5,
    cls=0.5,
    dfl=1.5,

    mosaic=1.0,
    close_mosaic=10,
    mixup=0.05,
    hsv_h=0.015,
    hsv_s=0.7,
    hsv_v=0.4,
    flipud=0.0,
    fliplr=0.5,
    scale=0.3,
    degrees=0.0,
    translate=0.1,

    patience=30,
    save_period=10,
    seed=0,
    amp=True,
    project='runs/train',
    name='custom_yolo_experiment',
    save=True,
    plots=True,
    val=True,
)

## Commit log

2024-08-09 Initial commit: Master files have been added
    [EBA_01.00.001.STL, EBA_01.00.002_vertical_drive_arm.STL, EBA_01.00.003_link.STL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]
2024-09-14 Fixed bugs, changed code style, added 3D models
    [EBA_01.00.010_basement.stl, EBA_01.00.013_R01_right_finger.stl, EBA_01.00.014_R01_left_finger.stl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]
2024-09-22 3D models renamed
    [OWN_01.00.017_platform.stl, OWN_01.00.018_esp32_cam_holder.stl, OWN_01.00.019_box_bottom_cover.stl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]
2024-10-10 The project is reformatted under 'dataset-v3'
    [metrics.csv]
2024-11-17 ChantGPT API filter added in app
2024-11-24 Filter by image added, error handlers added
2025-06-24 Arm logic updated to support flashlight
2025-06-24 Arduino flashlight support added
2025-08-18 3D models updated
    [OWN_01.00.019_bottom_panel_legs.stl, OWN_01.00.019_box_bottom_cover.stl, OWN_01.00.020_box_side_cover.stl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]
2025-12-27 Custom model and layers with instructions for it added
    [metrics.csv, params.txt]
2025-12-27 Documentations updated
    [params.txt]
2026-04-05 3D models updated to ensure the newest physical construction design view
    [OWN_01.00.019_bottom_panel_legs.stl, OWN_01.00.020_box_side_cover_v2.stl, OWN_01.00.021_display_mount.stl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]
2026-04-12 Small documentations and logic corrections added for Arduino and Multimodal Chatbot sections
    [servos_and_led.ino]
2026-04-24 Learning parameters for YOLOv8 and YOLOv10 models corrected
    [params.txt]
2026-05-15 LED reflector 3D model added
    [OWN_01.00.037_led_reflector.stl]
